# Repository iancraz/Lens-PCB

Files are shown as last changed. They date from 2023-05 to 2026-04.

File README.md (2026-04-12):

# Lens-Maker PCB
<a rel="license" href="http://creativecommons.org/licenses/by-nc-sa/4.0/">Creative Commons License</a><br />

This repository contains the design files for a printed circuit board (PCB) that enables the control of three stepper motors using an A4988 driver and an ESP32-WROOM32E microcontroller module. The PCB provides a compact and convenient solution for incorporating stepper motor control into your projects.

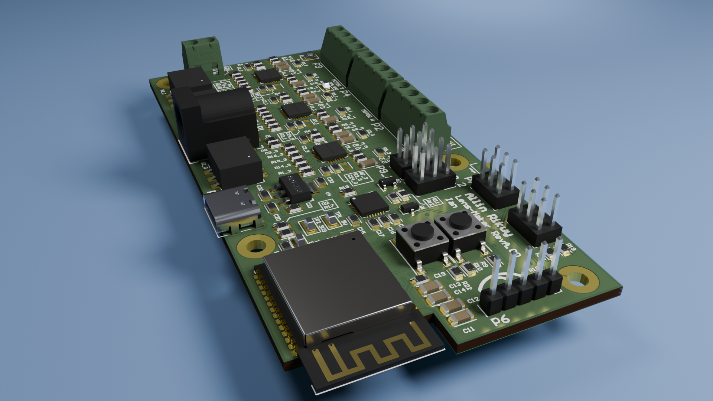
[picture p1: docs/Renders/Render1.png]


# Table of contents

* [Overview](#overview)
* [Features](#features)
* [Repository Structure](#repository-structure)
* [PCB Design](#pcb-design)
* [Bill of Materials (BOM)](#bill-of-materials)
* [Fabrication Instructions](#fabrication-instructions)
* [Contributing](#contributing)
* [License](#license)

## Overview
>[Table of contents](#table-of-contents)

The purpose of this PCB design is to simplify the process of controlling three stepper motors in your projects. By integrating an A4988 driver and an ESP32-WROOM32E module on a single board, you can easily interface with the motors and leverage the features of the ESP32 for advanced control and communication capabilities. In this design in particular three 2(A) stepper motors where needed to be controlled for a lens maker lathe, and the PCB was designed to fit the casing of the lathe.

# Features
>[Table of contents](#table-of-contents)

* **Compact**: The PCB is designed to be as small as possible while still providing the necessary features for stepper motor control.
* **Integrated A4988 Driver**: The A4988 driver is integrated into the PCB, eliminating the need for a separate driver module.
* **Integrated ESP32-WROOM32E Module**: The ESP32-WROOM32E module is integrated into the PCB, eliminating the need for a separate microcontroller module.
* **Integrated WiFi and Bluetooth Antennas**: The ESP32-WROOM32E module includes integrated WiFi and Bluetooth antennas, eliminating the need for external antennas.
* **Integrated Power Supply**: The PCB includes a 5V power supply that can be used to power the ESP32-WROOM32E module and the A4988 driver.
* **Integrated USB to UART Converter**: The PCB includes a USB to UART converter that can be used to program the ESP32-WROOM32E module and communicate with it via serial.
* **Integrated Reset Button**: The PCB includes a reset button that can be used to reset the ESP32-WROOM32E module.
* **I2C, SPI and GPIO Headers**: The PCB includes headers that can be used to connect I2C, SPI and GPIO devices to the ESP32-WROOM32E module.
* **JTAG Header**: The PCB includes a header that can be used to connect a JTAG debugger to the ESP32-WROOM32E module.
* **USB-C Connector**: The PCB includes a USB-C connector that can be used to power the PCB and communicate with the ESP32-WROOM32E module via USB.

# Repository Structure
>[Table of contents](#table-of-contents)

The repository is organized as follows:

* **`Lens-Maker`**: This directory contains the Altium design files for the PCB.
    * **`Project Outputs for Lens-Maker`**: This directory contains the Output files of the project.
        * **`GerberX2`**: This directory contains the Gerber files of the PCB.
        * **`Lens-Maker_Schematic.PDF`**: This file contains the PDF of the PCB.
        * **`ExportSTEP`**: This directory contains the 3D model of the PCB.
        * **`BOM`**: This directory contains the Bill of Materials of the PCB. 
* **`docs`**: This directory contains the documentation images for the PCB.
* **`LICENSE`**: This file contains the license for the PCB design.
* **`README.md`**: This file contains the documentation for the PCB design.

# PCB Design
>[Table of contents](#table-of-contents)

This PCB was design using Altium Designer 23.4.1. The PCB design files can be found in [here](./Lens-Maker). The PCB was designed to be as small as possible while still providing the necessary features for stepper motor control. The PCB is a 6-layer board with the following stackup:

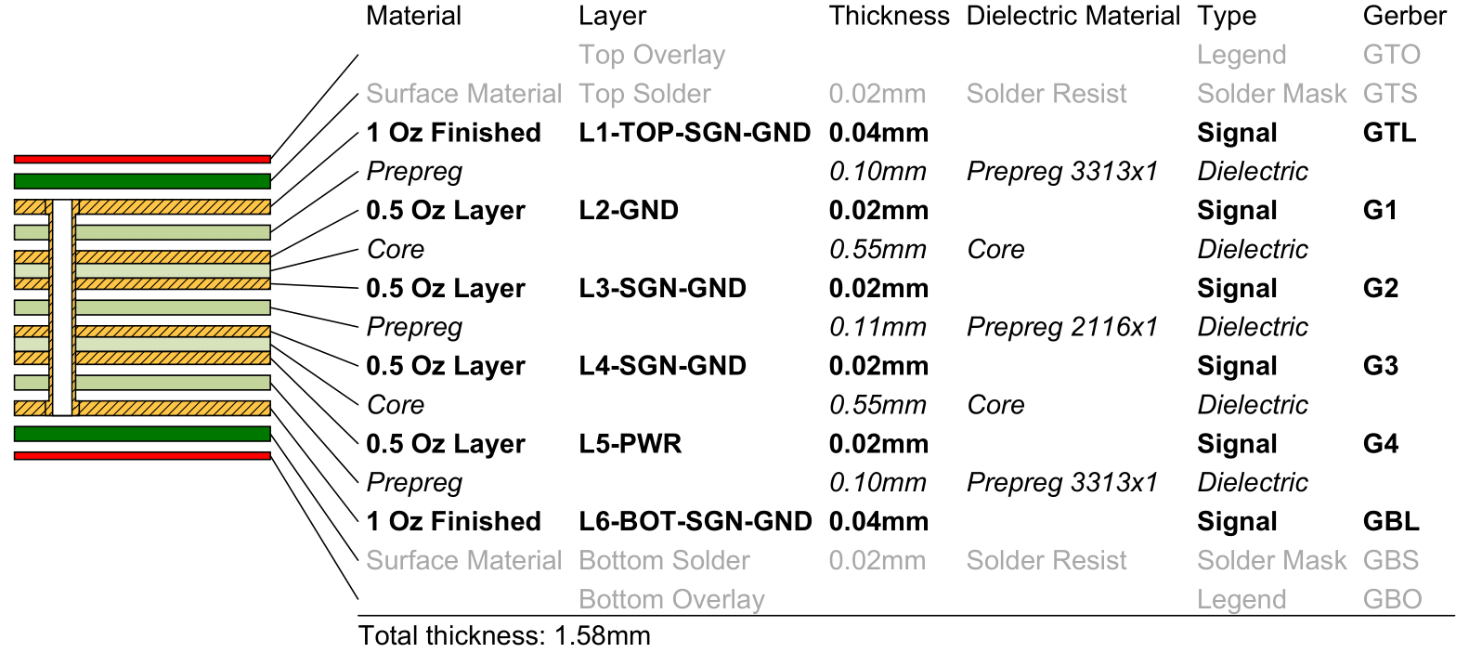
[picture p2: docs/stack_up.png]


The PCB was designed to fit the casing of the lens maker lathe, and the dimensions of the PCB are as follows:

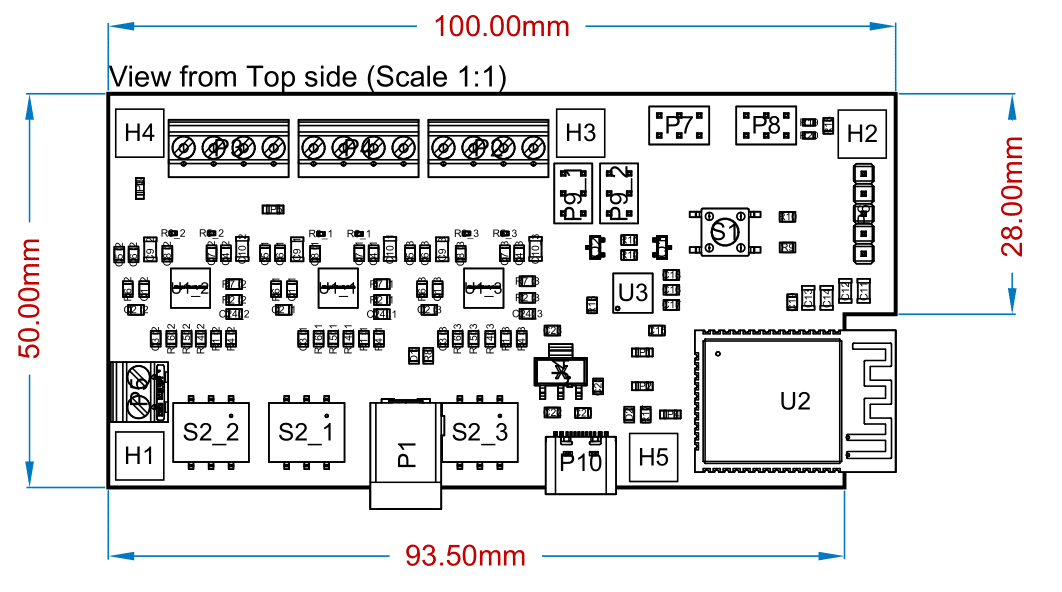
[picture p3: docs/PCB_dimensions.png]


## Microcontroller
>[Design](#design)

The design of this PCB starts at the desition of the MCU chosen for this purpose. Because of its simplicity and WiFi and Bluetooth antennas already integrated, an ESP32-WROOM-32E is chosen for this design. The main advantages of choosing this microcontroller are:

* **The form factor**: Its a MCU with WLAN capabilities in a size of a regular MCU.
* **Antennas integrated**: The benefits of using an ESP32 module and not an ESP32 MCU is to have the antennas already routed an integrated.
* **Easy to use**: Its many integration generated that ESP32 is a widely used MCU around the world, and this means there's a lot of information and resources to program this MCU.
* **Versatility**: If there is a future design, a new ESP32 module can be changed and the software will 'just work'.

## Stepper Driver
>[Design](#design)

For the Stepper driver, since this design is a prototype approach for the final goal, an A4988 driver was chosen, because of its previous use on a concept desing using the A4988 module from arduino. For future progress a driver change is needed to drive more heavy power Stepper motors. However this driver has a lot of advantages, its ease of use and simplicity makes it really easy tu use and code it, and its application in its own module has the heritage needed for the circuit to rely on.

## Schematic
>[Table of contents](#table-of-contents)

The Schematic of this PCB can be found in [here](./Lens-Maker/Project%20Outputs%20for%20Lens-Maker/Lens-Maker_Schematic.PDF). And below are some images sumarizing it. 

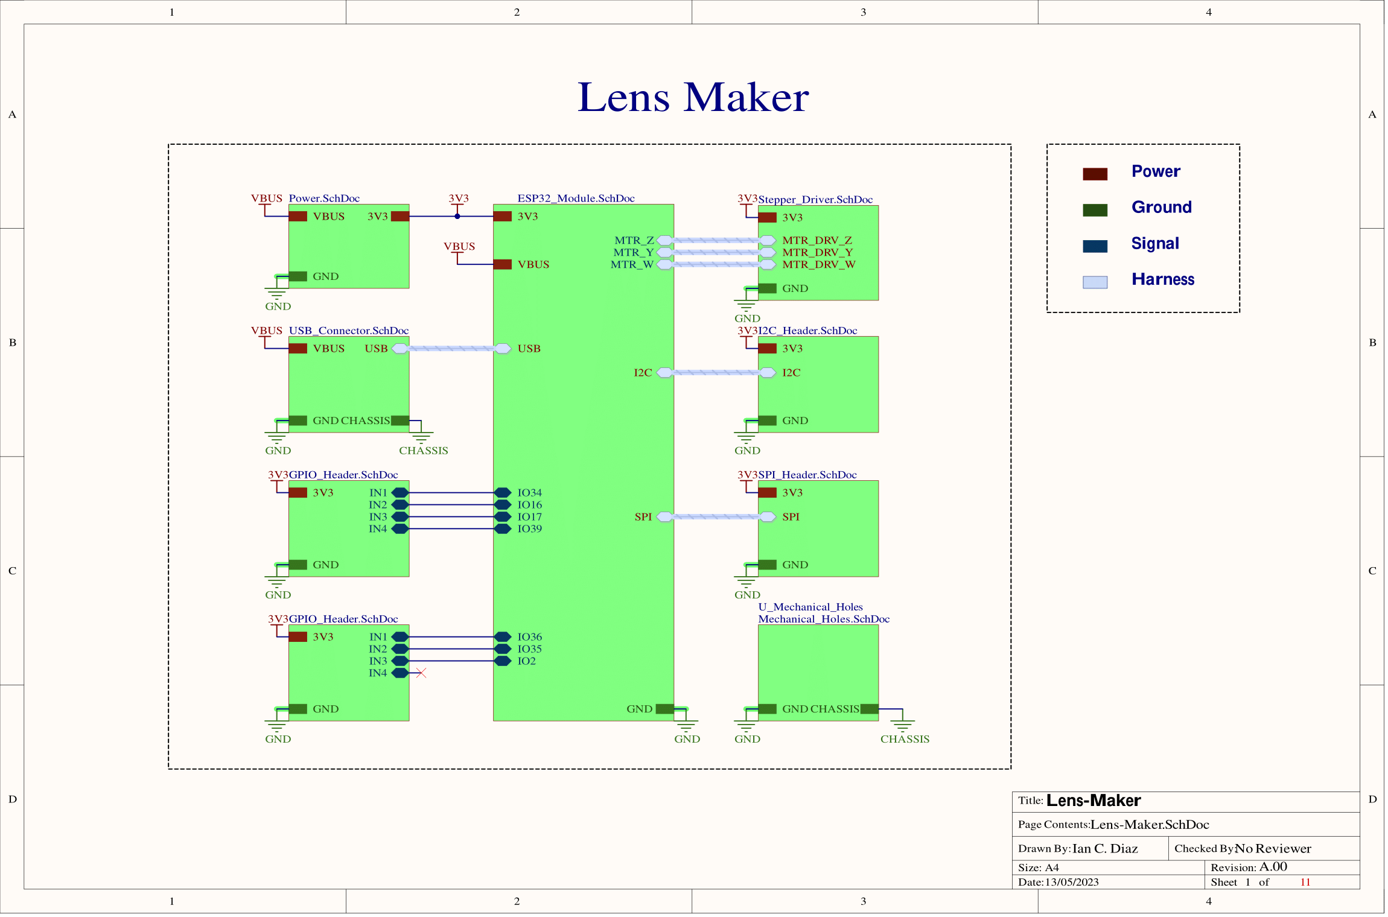
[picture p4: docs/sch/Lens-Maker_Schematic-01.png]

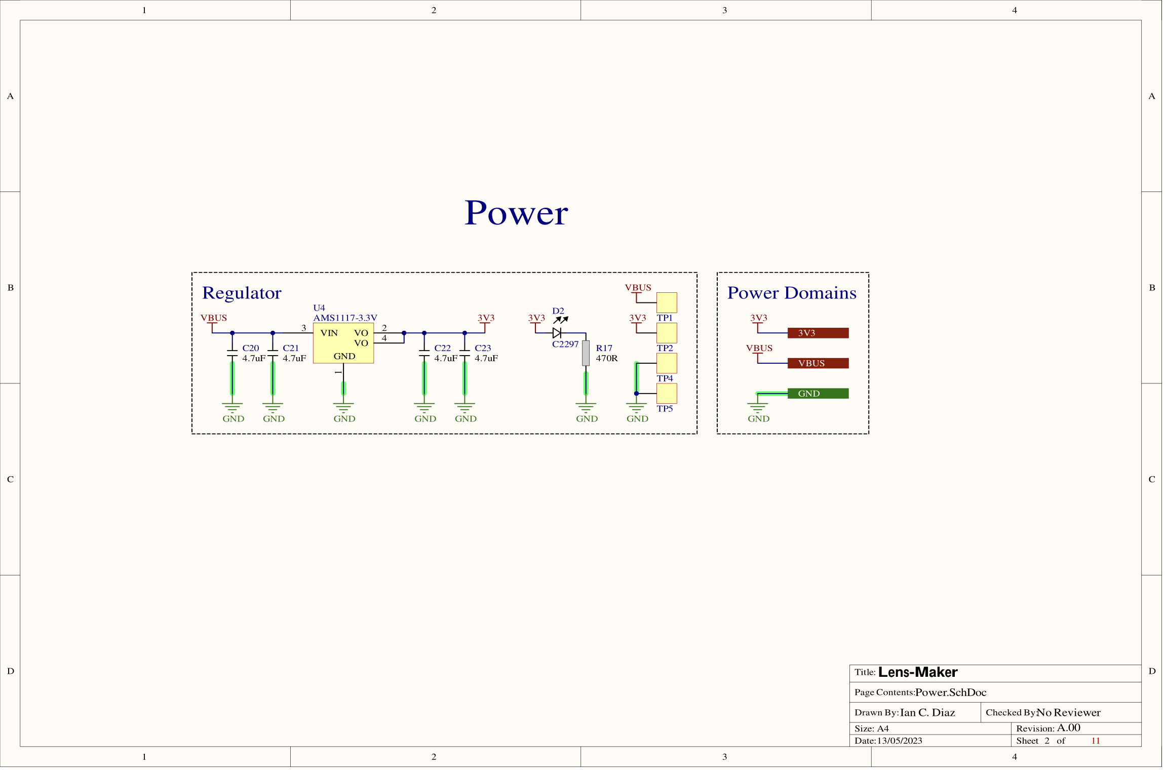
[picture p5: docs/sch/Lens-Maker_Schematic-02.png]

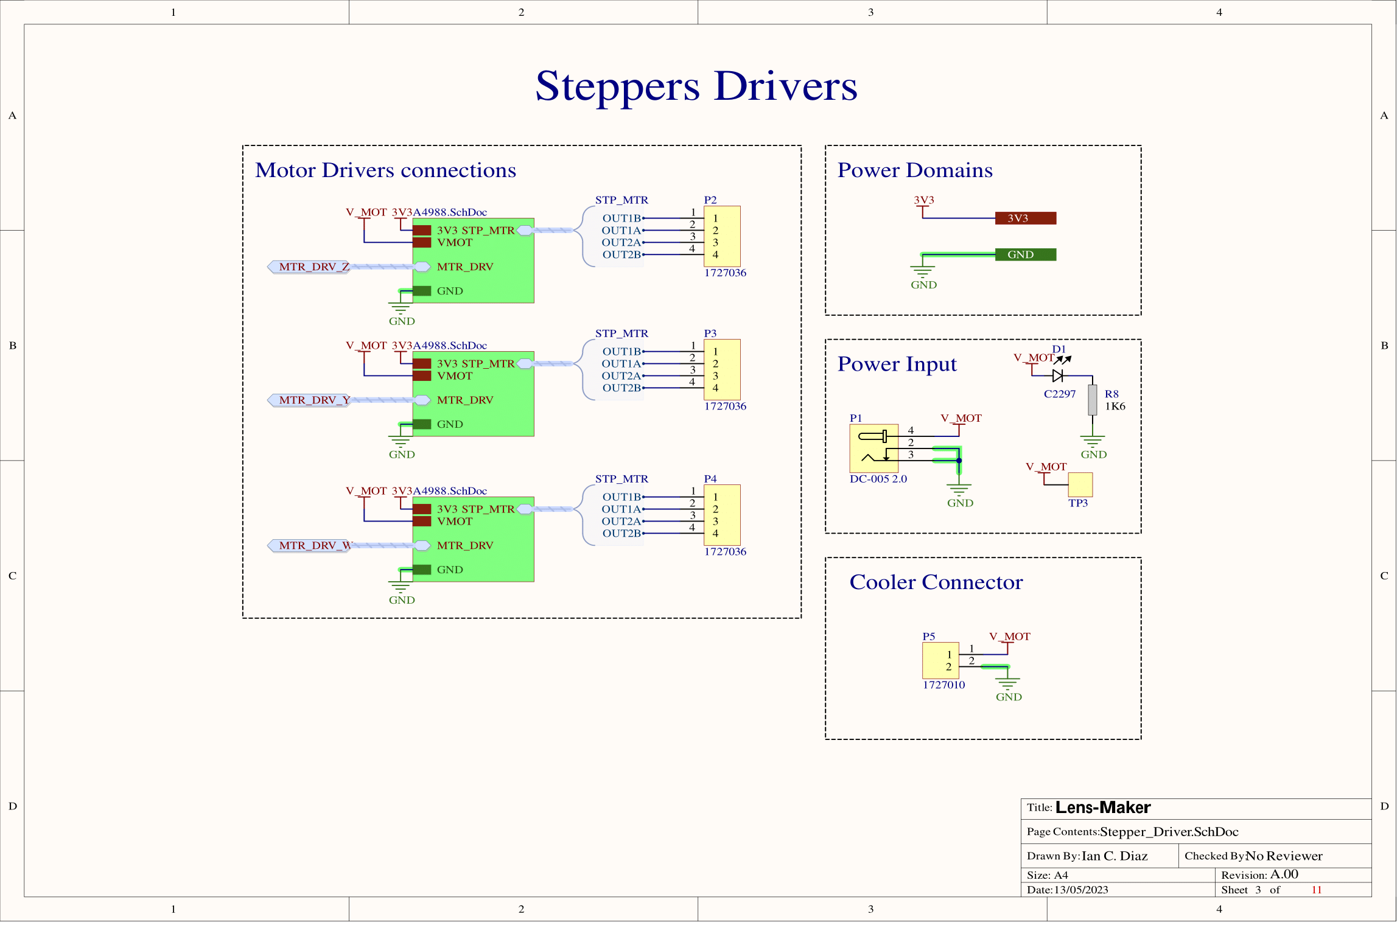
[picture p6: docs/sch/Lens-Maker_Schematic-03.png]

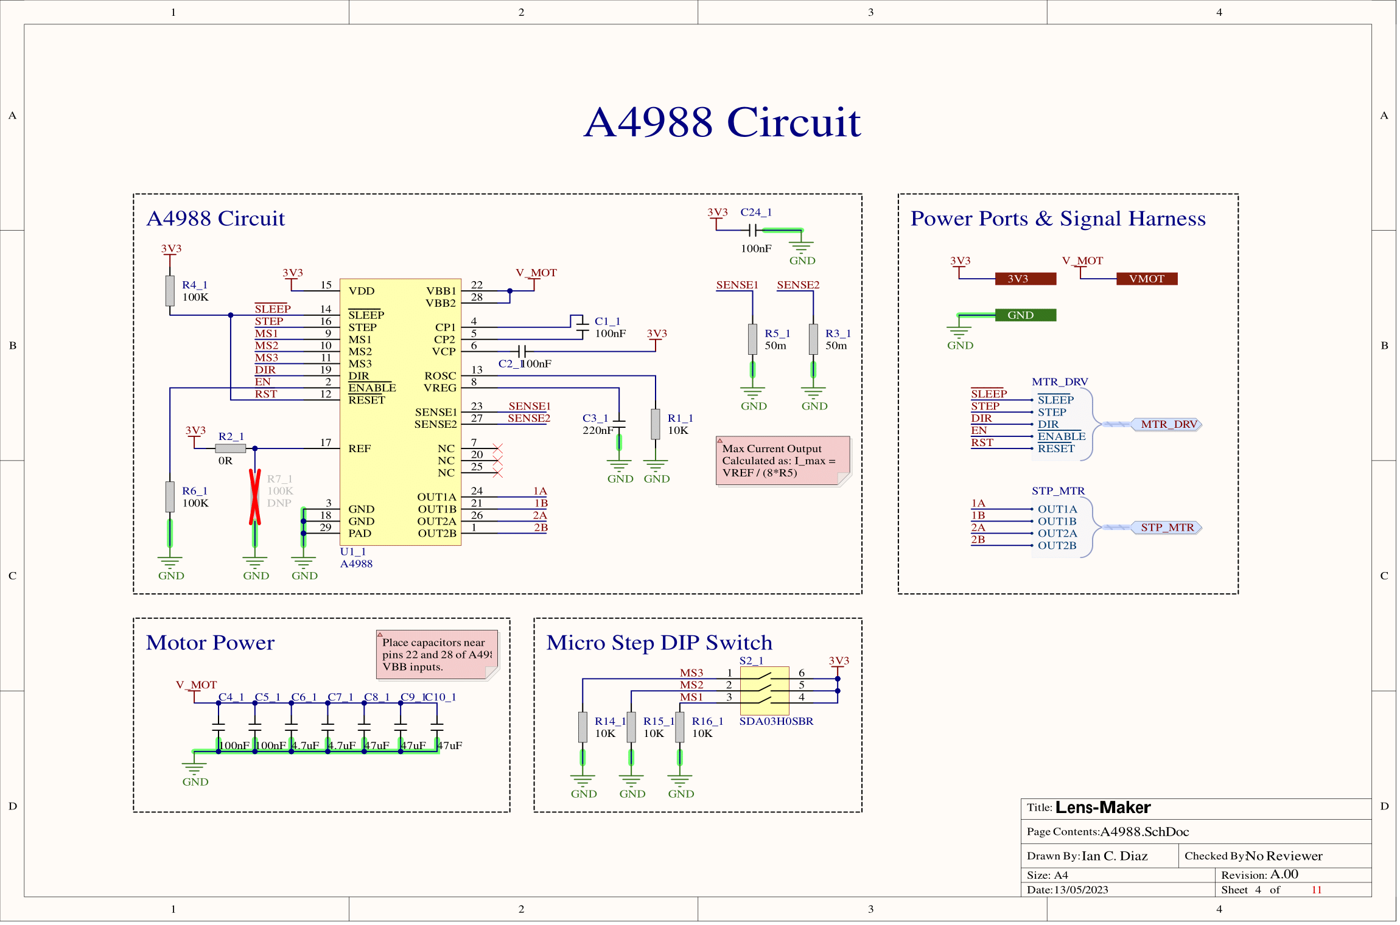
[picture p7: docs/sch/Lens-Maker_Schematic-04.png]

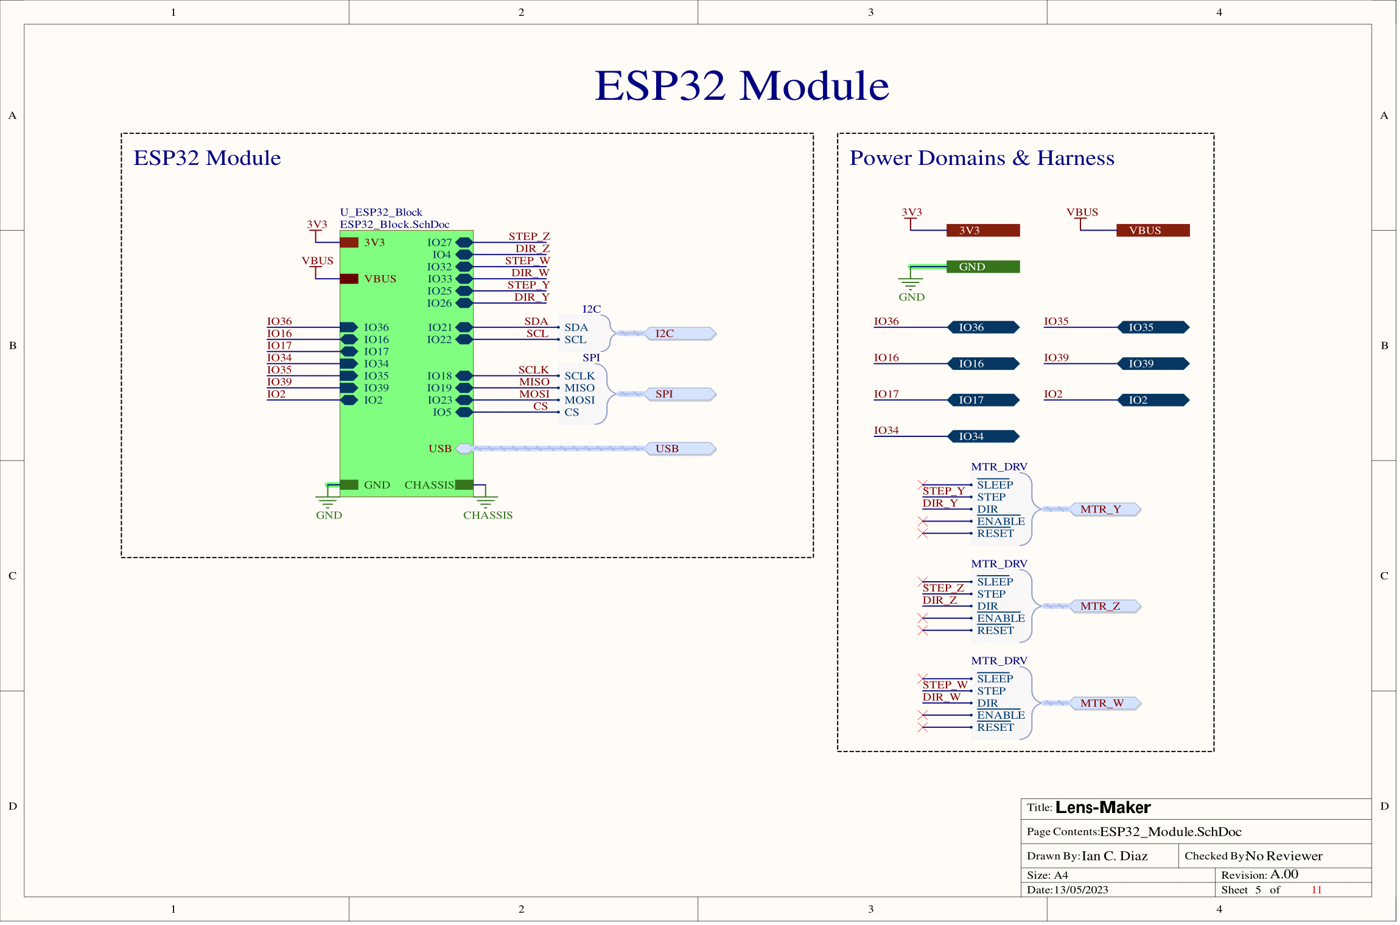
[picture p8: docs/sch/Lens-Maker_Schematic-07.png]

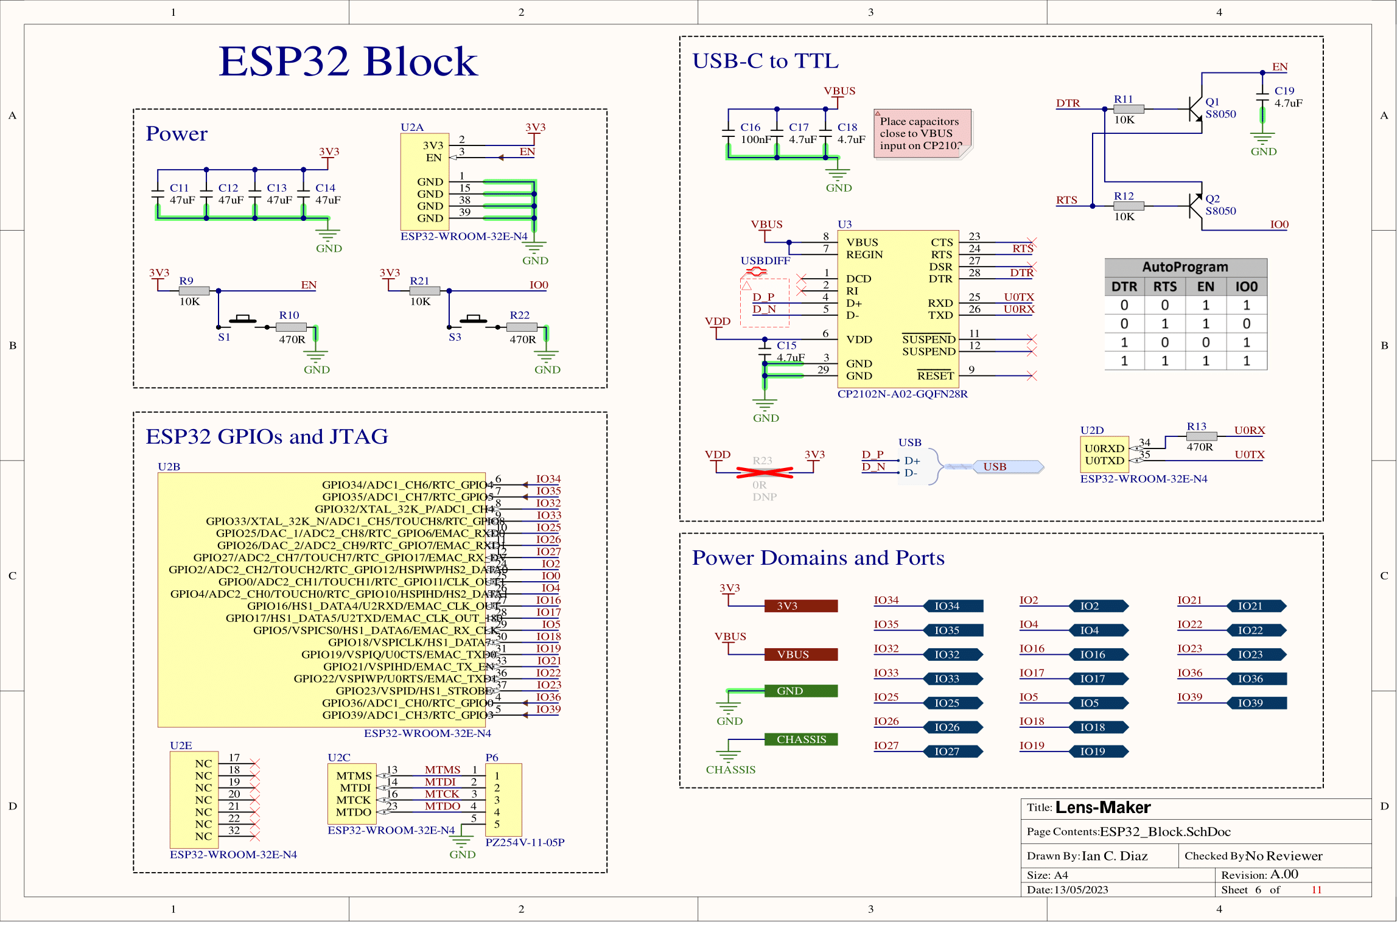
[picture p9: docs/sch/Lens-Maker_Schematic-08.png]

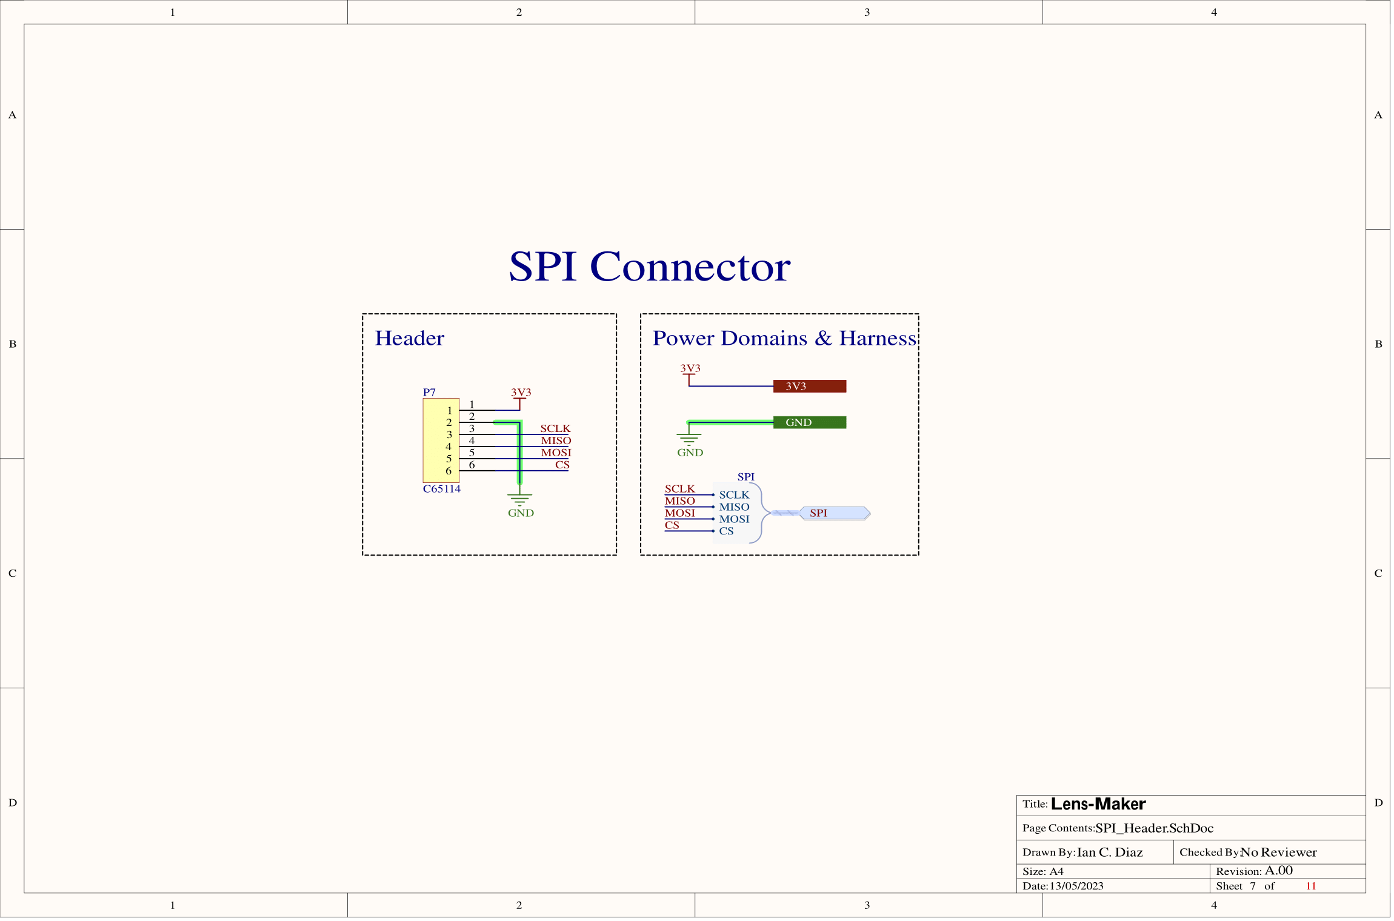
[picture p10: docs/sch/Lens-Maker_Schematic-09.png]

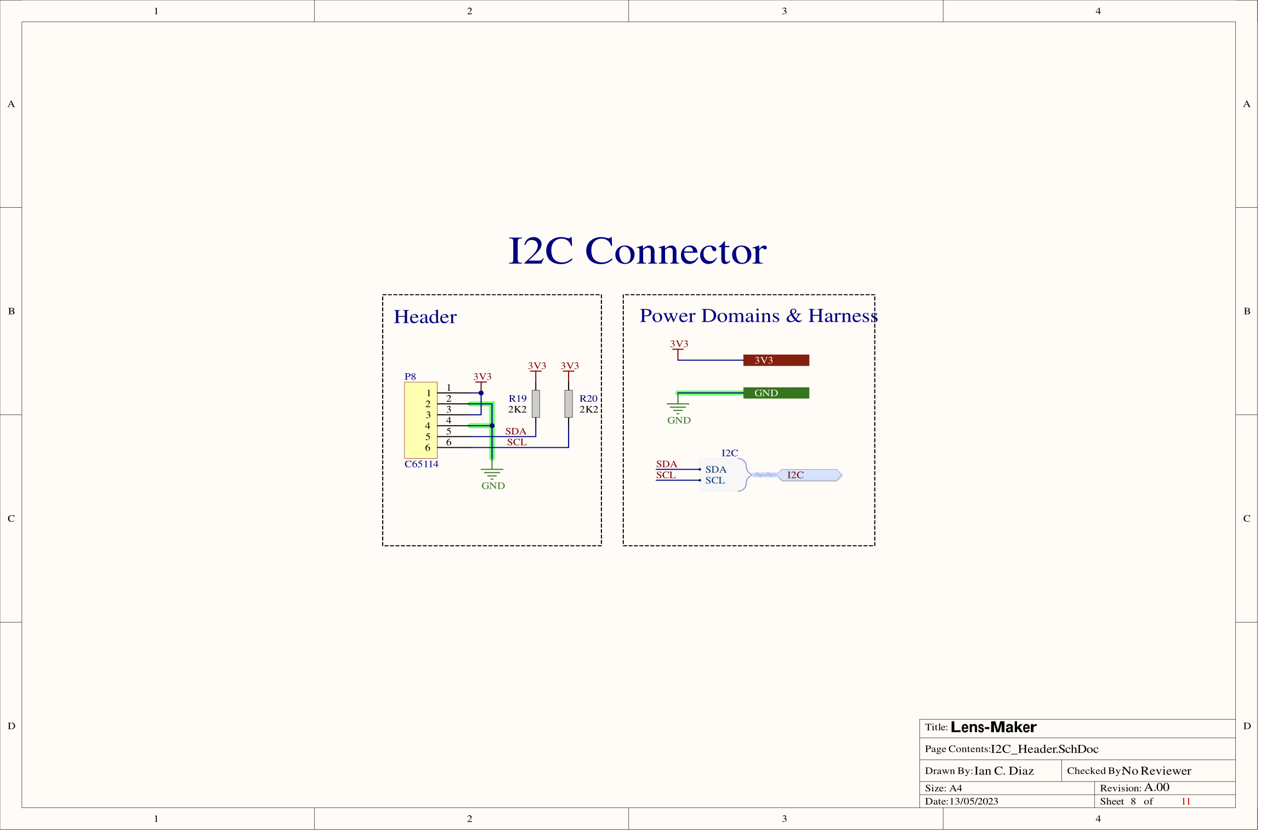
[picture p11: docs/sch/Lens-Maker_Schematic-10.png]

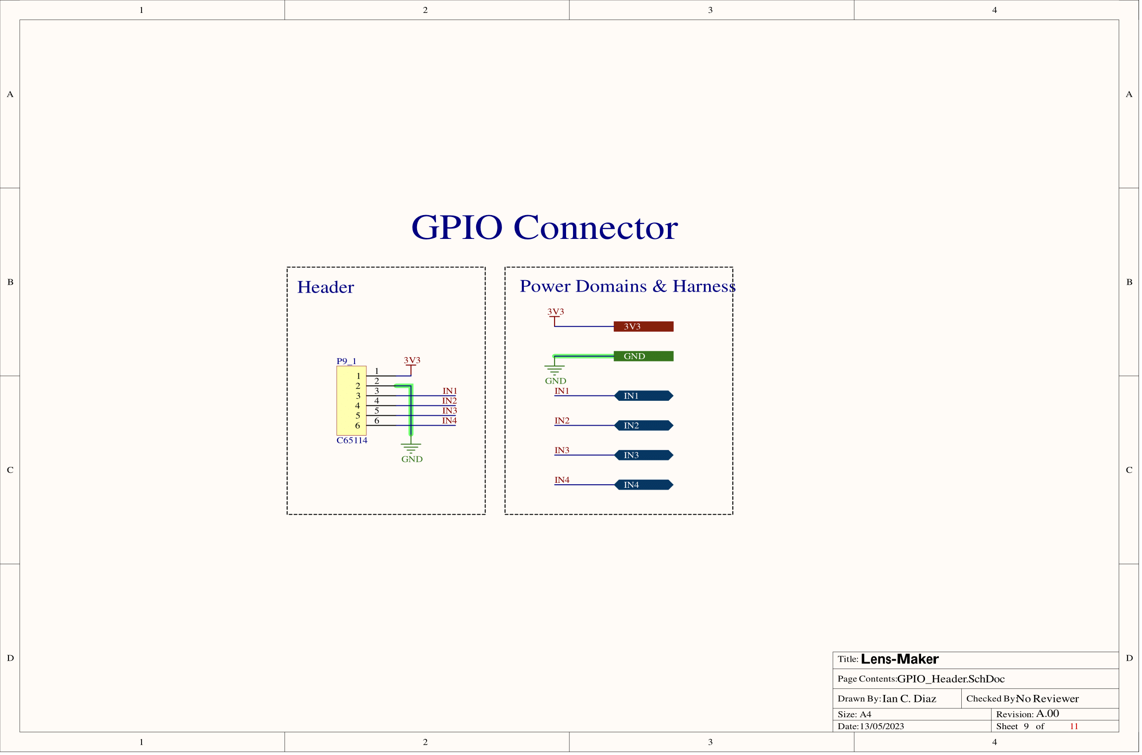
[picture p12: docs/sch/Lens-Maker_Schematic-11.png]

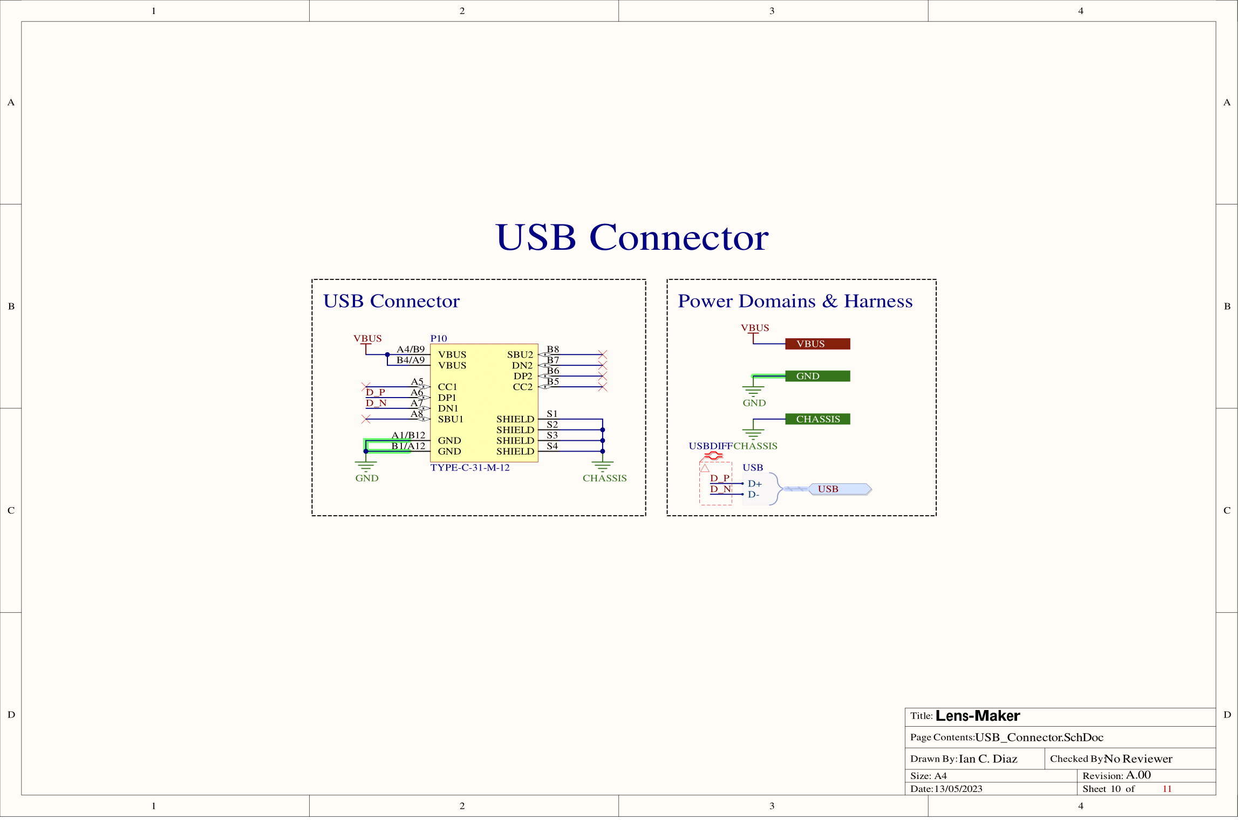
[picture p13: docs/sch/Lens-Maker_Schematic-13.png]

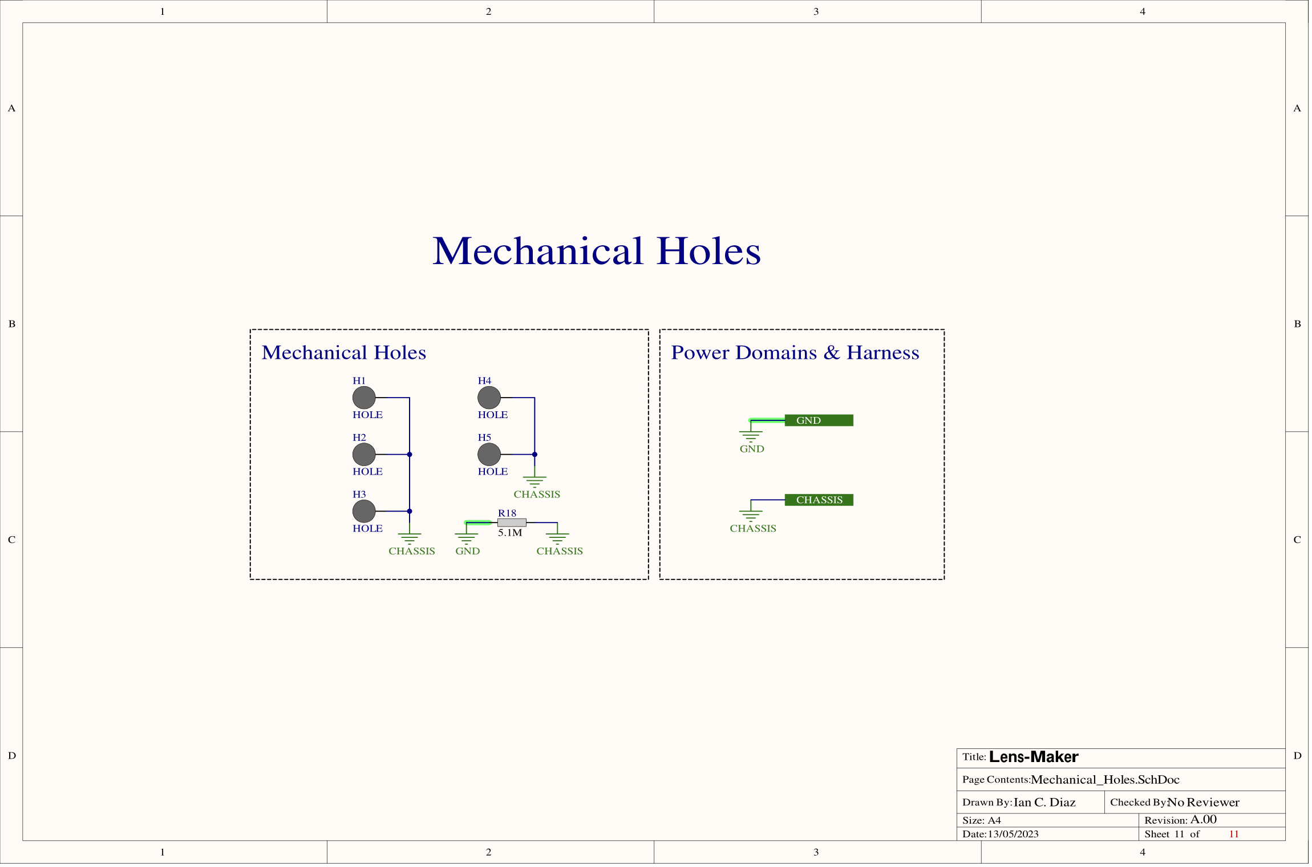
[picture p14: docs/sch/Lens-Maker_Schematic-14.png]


# Bill of Materials
>[Table of contents](#table-of-contents)

| Designator | Footprint | Value | Manufacturer | Manufacturer Part Number | Supplier | Supplier Part Number | Description | Quantity |
| --- | --- | ----- | --- | --- | --- | --- | --- | --- |
| C1_1, C1_2, C1_3, C2_1, C2_2, C2_3, C4_1, C4_2, C4_3, C5_1, C5_2, C5_3, C16, C24_1, C24_2, C24_3 | 0805 | 100nF | YAGEO | CC0805KRX7R9BB104 | JLCPCB | C49678 | 50V 100nF X7R ±10% 0805 Multilayer Ceramic Capacitors MLCC - SMD/SMT ROHS | 16 |
| C3_1, C3_2, C3_3 | 0805 | 220nF | Samsung Electro-Mechanics | CL21B224KBFNNNE | JLCPCB | C5378 | 50V 220nF X7R ±10% 0805 Multilayer Ceramic Capacitors MLCC - SMD/SMT ROHS | 3 |
| C6_1, C6_2, C6_3, C7_1, C7_2, C7_3, C15, C17, C18, C19, C20, C21, C22, C23 | 0805 | 4.7uF | Samwha Capacitor | CS2012X7R475K350NRE | JLCPCB | C560882 | 35V 4.7uF X7R ±10% 0805 Multilayer Ceramic Capacitors MLCC - SMD/SMT ROHS | 14 |
| C8_1, C8_2, C8_3, C9_1, C9_2, C9_3, C10_1, C10_2, C10_3, C11, C12, C13, C14 | 1206 | 47uF  | TDK | C3216X5R1E476MTJ00E | JLCPCB | C76659 | 25V 47uF X5R ±20% 1206 Multilayer Ceramic Capacitors MLCC - SMD/SMT ROHS | 13 |
| D1, D2 | 0805 | | Hubei KENTO Elec | C2297 | JLCPCB | C2297 | 0805 Light Emitting Diodes (LED) ROHS | 2 |
| H1, H2, H3, H4, H5 | HOLE_M3 | | | | | | Hole M3 | 5 |
| P1 | DC-005 2.0 | | BOOMELE(Boom Precision Elec) | DC-005 2.0 | JLCPCB | C16214 | Shrouded DC Power Receptacle 2mm 6.4mm Plugin AC/DC Power Connectors ROHS | 1 |
| P2, P3, P4 | 1727036 | | Phoenix Contact | 1727036 | JLCPCB | C457200 | TERM BLK 4P SIDE ENT 3.81MM PCB | 3 |
| P5 | 1727010 | | Phoenix Contact | 1727010 | JLCPCB | C89123 | TERM BLK 2P SIDE ENT 3.81MM PCB | 1 |
| P6 | PZ254V-11-05P | | XFCN | PZ254V-11-05P | JLCPCB | C492404 | Straight Square Pins 2.5mm 6mm -40℃~+105℃ 3mm 5 2.54mm Black Brass 1x5P Plugin,P=2.54mm Pin Headers ROHS | 1 |
| P7, P8, P9_1, P9_2 | HEADER 3X2 | | BOOMELE(Boom Precision Elec) | C65114 | JLCPCB | C65114 | Straight 2 6 2.54mm Black Straight,P=2.54mm Pin Headers ROHS | 4 |
| P10 | TYPE-C-31-M-12  | | Korean Hroparts Elec | TYPE-C-31-M-12 | JLCPCB | C165948 | USB C SMD Connector | 1 |
| Q1, Q2 | SOT-23-3 | | JSMSEMI | S8050 | JLCPCB | C916390 | 25V 300mW 500mA SOT-23 Bipolar Transistors - BJT ROHS | 2 |
| R1_1, R1_2, R1_3, R9, R11, R12, R14_1, R14_2, R14_3, R15_1, R15_2, R15_3, R16_1, R16_2, R16_3, R21 | 0805 | 10K | UNI-ROYAL(Uniroyal Elec) | 0805W8F1002T5E | JLCPCB | C17414 | 125mW Thick Film Resistors ±1% 10kΩ 0805 Chip Resistor - Surface Mount ROHS | 16 |
| R2_1, R2_2, R2_3 | 0805 | 0R | PANASONIC | ERJ6GEY0R00V | JLCPCB | C169855 | 125mW 0Ω 0805 Chip Resistor - Surface Mount ROHS | 3 |
| R3_1, R3_2, R3_3, R5_1, R5_2, R5_3 | 0805 | 50m | YAGEO | PE0805FRF7W0R05L | JLCPCB | C858613 | 250mW ±1% 50mΩ 0805 Chip Resistor - Surface Mount ROHS | 6 |
| R4_1, R4_2, R4_3, R6_1, R6_2, R6_3 | 0805 | 100K  | FH (Guangdong Fenghua Advanced Tech) | RS-05K104JT | JLCPCB | C118844 | 125mW ±5% 100kΩ 0805 Chip Resistor - Surface Mount ROHS | 6 |
| R8 | 0805 | 1K6 | Resistor.Today | AECR0805F1K60K9 | JLCPCB | C352253 | 125mW Thick Film Resistors ±1% 1.6kΩ 0805 Chip Resistor - Surface Mount ROHS | 1 |
| R10, R13, R17, R22 | 0805 | 470R  | UNI-ROYAL(Uniroyal Elec) | 0805W8F4700T5E | JLCPCB | C17710 | 125mW Thick Film Resistors ±1% 470Ω 0805 Chip Resistor - Surface Mount ROHS | 4 |
| R18 | 0805 | 5.1M  | TA-I Tech | RM10FTN5104 | JLCPCB | C156163 | 125mW Thick Film Resistors ±1% 5.1MΩ 0805 Chip Resistor - Surface Mount ROHS | 1 |
| R19, R20 | 0805 | 2K2 | LIZ Elec | CR0805J80222G | JLCPCB | C101970 | 125mW Thick Film Resistors ±5% 2.2kΩ 0805 Chip Resistor - Surface Mount ROHS | 2 |
| S1, S3 | PUSHBUTTON_2 | | C&K | PTS645SM43SMTR92LFS | JLCPCB | C221880 | SWITCH TACTILE SPST-NO 0.05A 12V | 2 |
| S2_1, S2_2, S2_3 | SDA03H0SBR | | C&K | SDA03H0SBR | JLCPCB | C221950 | SWITCH SLIDE DIP SPST 25MA 24V | 3 |
| TP1, TP2, TP3, TP4, TP5 | 5015 | | Ronghe | RH-5015 | JLCPCB | C5199798 | Thimble/Copper Rod/Test Ring ROHS | 5 |
| U1_1, U1_2, U1_3 | 28-QFN | | Allegro MicroSystems, LLC | A4988SETTR-T | JLCPCB | C38437 | IC MTR DRVR BIPOLAR 3-5.5V 28QFN | 3 |
| U2 | ESP32-WROOM-32E | | Espressif Systems | ESP32-WROOM-32E-N4 | JLCPCB | C701341 | RX TXRX MOD WIFI TRACE ANT SMD | 1 |
| U3 | CP2102N | | SILICON LABS | CP2102N-A02-GQFN28R | JLCPCB | C964632 | QFN-28 USB ICs ROHS | 1 |
| U4 | SOT-223 | | Shenzhen Fuman Elec | AMS1117-3.3V | JLCPCB | C173386 | IC-1117 V.reg. 1A 3V3 SOT223 SMD Ams | 1 |

# Fabrication Instructions
>[Table of contents](#table-of-contents)

The fabrication instructions can be found in [here](./Lens-Maker/Project%20Outputs%20for%20Lens-Maker/Lens-Maker_Fabrication_Instructions.PDF) and the Gerber files are located in [this directory](./Lens-Maker/Project%20Outputs%20for%20Lens-Maker/GerberX2/). For the PCBA the assembly drawing can be found [here](./Lens-Maker/Project%20Outputs%20for%20Lens-Maker/Lens-Maker_Assembly_Drawings.PDF).

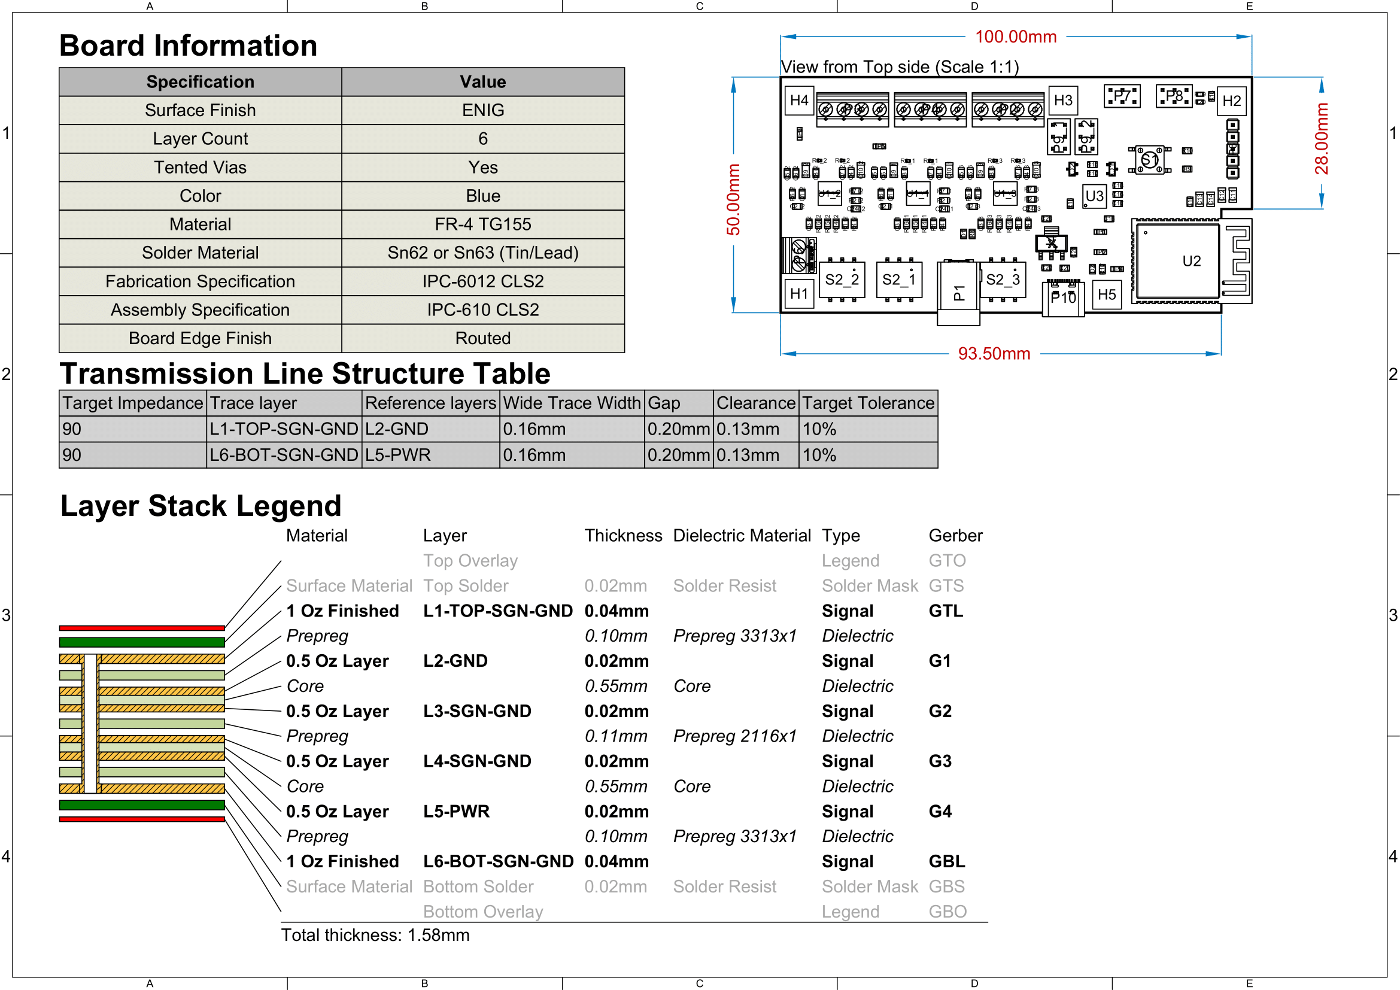
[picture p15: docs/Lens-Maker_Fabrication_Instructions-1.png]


## 3D Model
>[Table of contents](#table-of-contents)

A 3D model of the PCB is available for the design and manufacture of the lathe casing located in [here](./Lens-Maker/Project%20Outputs%20for%20Lens-Maker/ExportSTEP/Lens-Maker_3D_STEP.step).

## Some pictures
>[Table of contents](#table-of-contents)

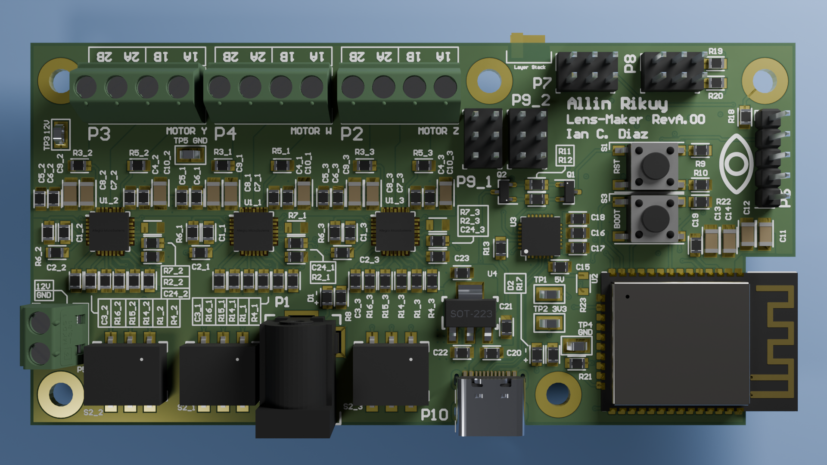
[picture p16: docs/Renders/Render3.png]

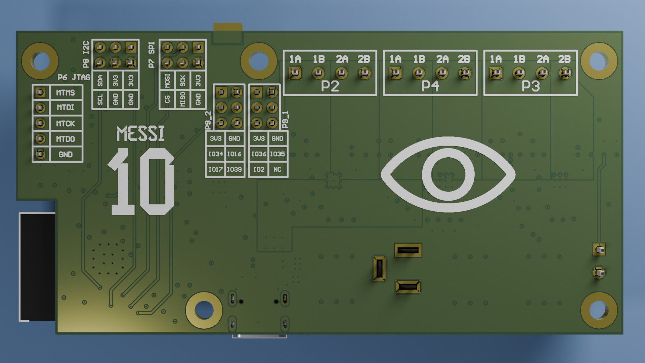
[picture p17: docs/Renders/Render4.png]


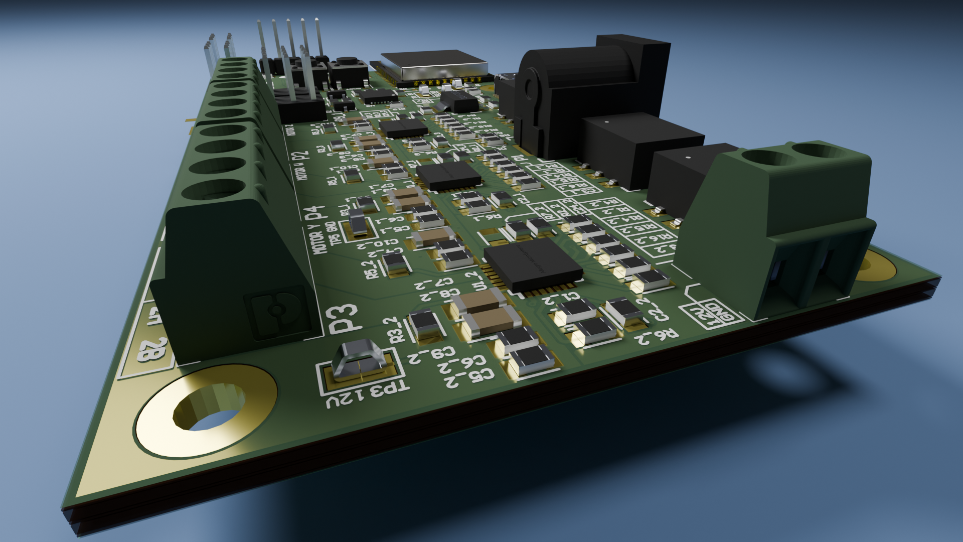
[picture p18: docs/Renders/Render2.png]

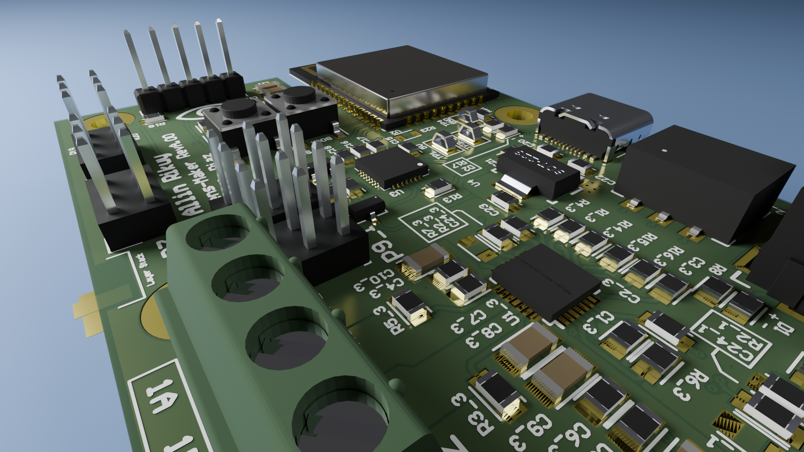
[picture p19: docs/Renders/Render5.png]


# Contributing
>[Table of contents](#table-of-contents)

Please do not hesitate to reach out to me if you find any issue with the code or if you have any questions.

* Personal email: [ianczdiaz@gmail.com](mailto:ianczdiaz@gmail.com)

* LinkedIn Profile: [https://www.linkedin.com/in/iancraz/](https://www.linkedin.com/in/iancraz/)

# License
>[Table of contents](#table-of-contents)

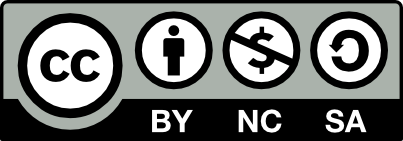
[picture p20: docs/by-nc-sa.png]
<br />

```
Copyright 2023 Ian Cruz Diaz. 

This project and all its components, including the PCB design files, Schematics and Output Files are 
licensed under a Creative Commons Attribution-NonCommercial-ShareAlike 4.0 International License. You 
can find a copy of the License at ./LICENSE.md or at https://creativecommons.org/licenses/by-nc-sa/4.0/legalcode.
```

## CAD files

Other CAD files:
docs/Renders/Project/Render.blend

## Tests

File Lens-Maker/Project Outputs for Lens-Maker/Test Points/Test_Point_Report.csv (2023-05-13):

Net | Name | X Coord | Y Coord | Side | Hole Size | Type
GND | TP5-1 | 823.969mil | 1390mil | Top | 0mil | Surface mount
VBUS | TP1-1 | 2670mil | 675mil | Top | 0mil | Surface mount
3V3 | TP2-1 | 2670mil | 526.52mil | Top | 0mil | Surface mount
V_MOT | TP3-1 | 157.481mil | 1495mil | Top | 0mil | Surface mount
GND | TP4-1 | 2810mil | 410.03mil | Top | 0mil | Surface mount

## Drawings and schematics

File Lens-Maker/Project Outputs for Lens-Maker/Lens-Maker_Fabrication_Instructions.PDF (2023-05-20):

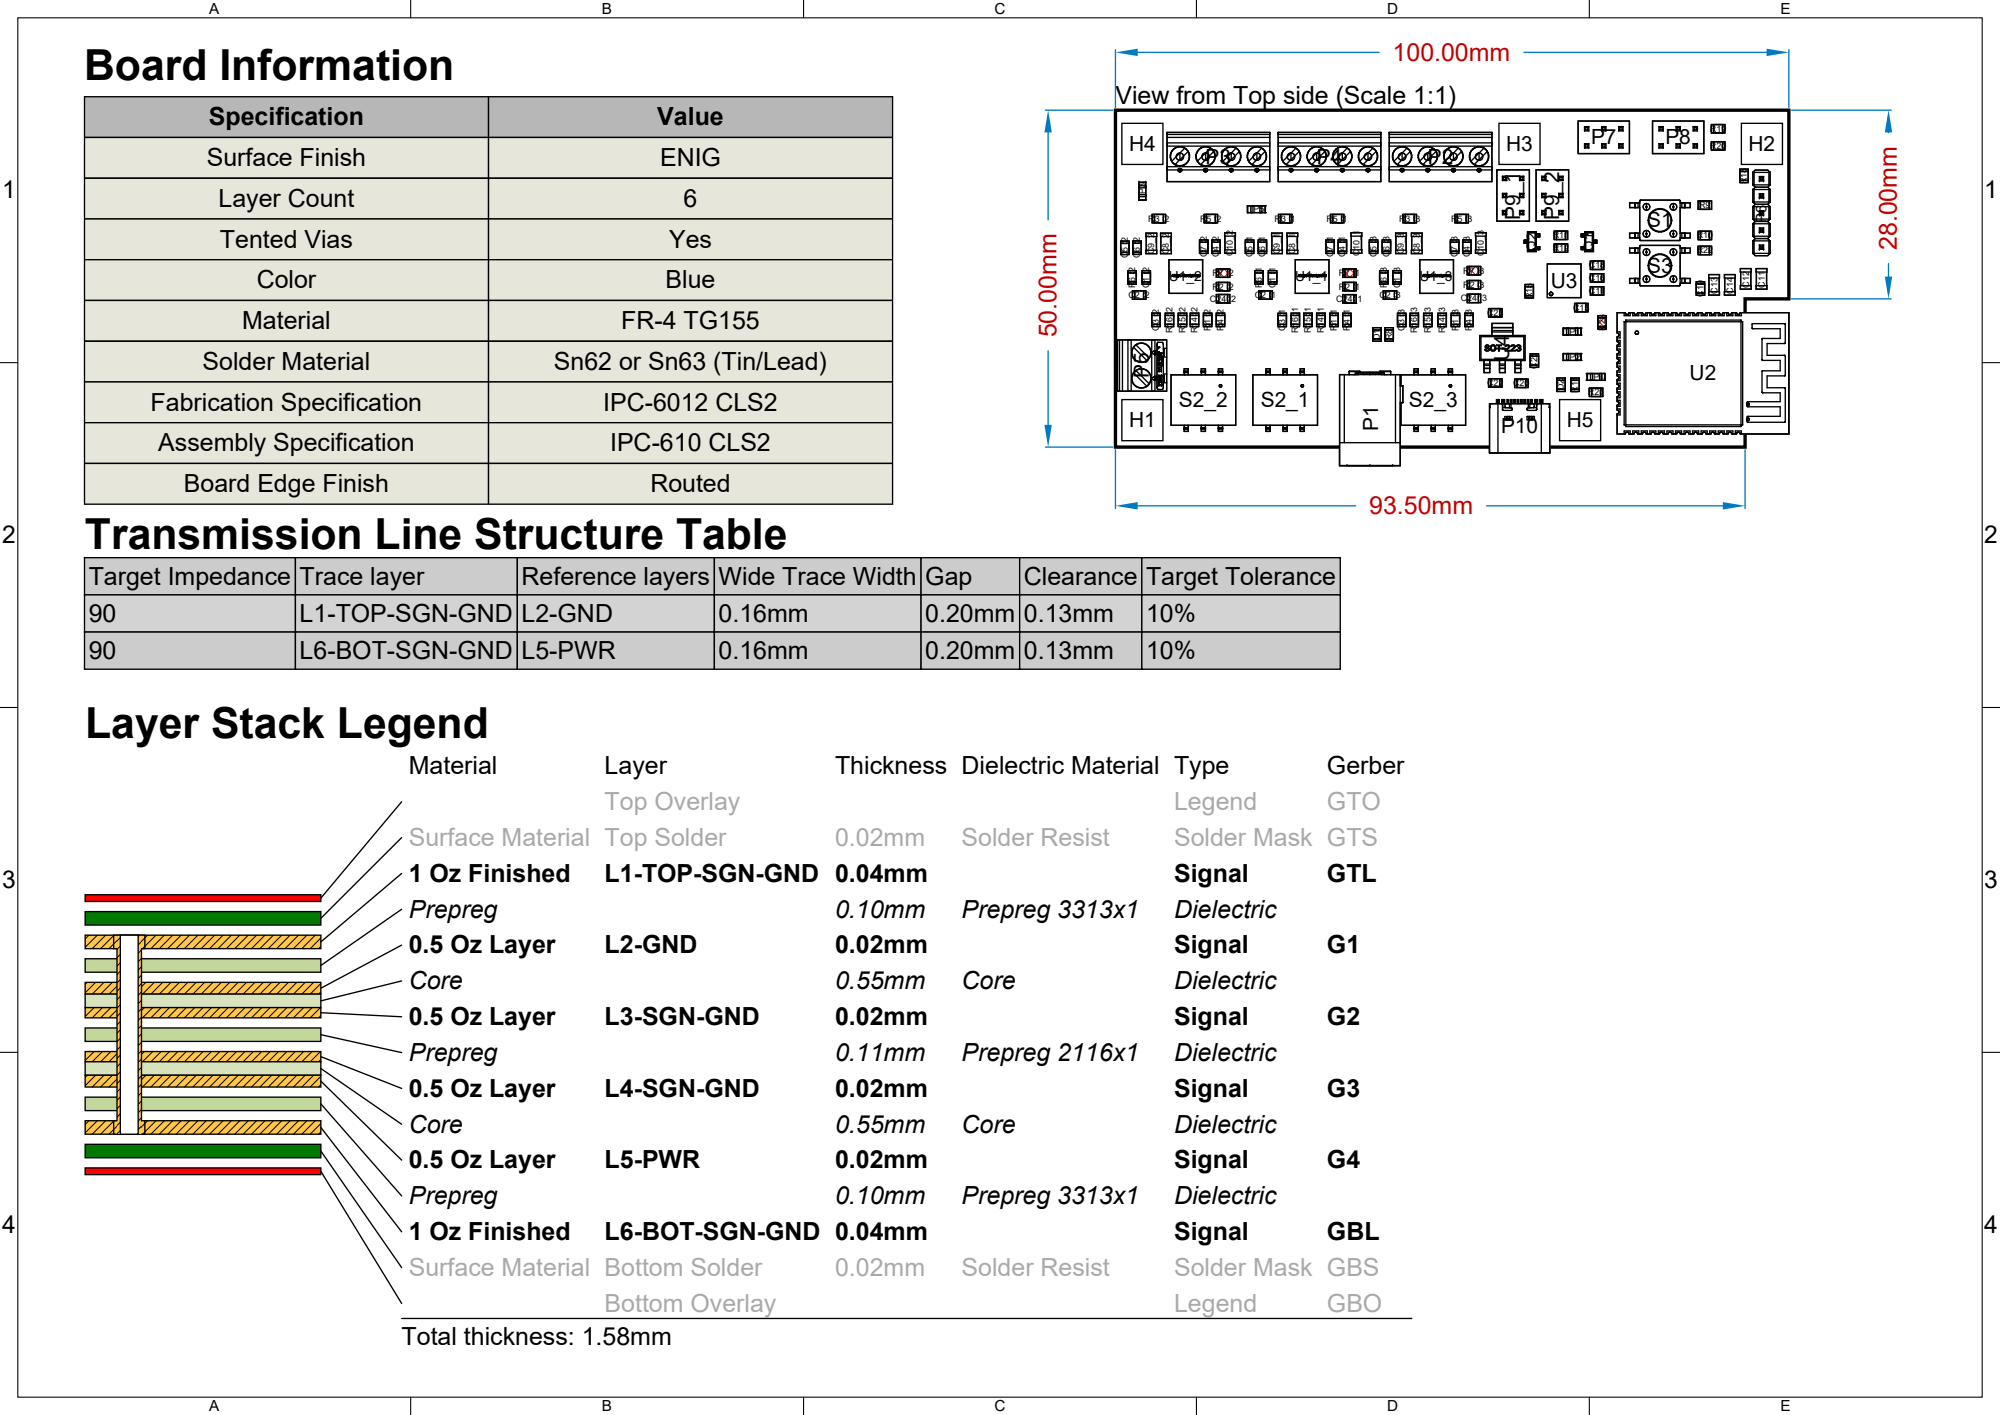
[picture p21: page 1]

View from Top side (Scale 1:1)

Solder Material
Fabrication Specification
Assembly Specification
Board Edge Finish
Transmission Line Structure Table
Target Impedance
Layer Stack Legend

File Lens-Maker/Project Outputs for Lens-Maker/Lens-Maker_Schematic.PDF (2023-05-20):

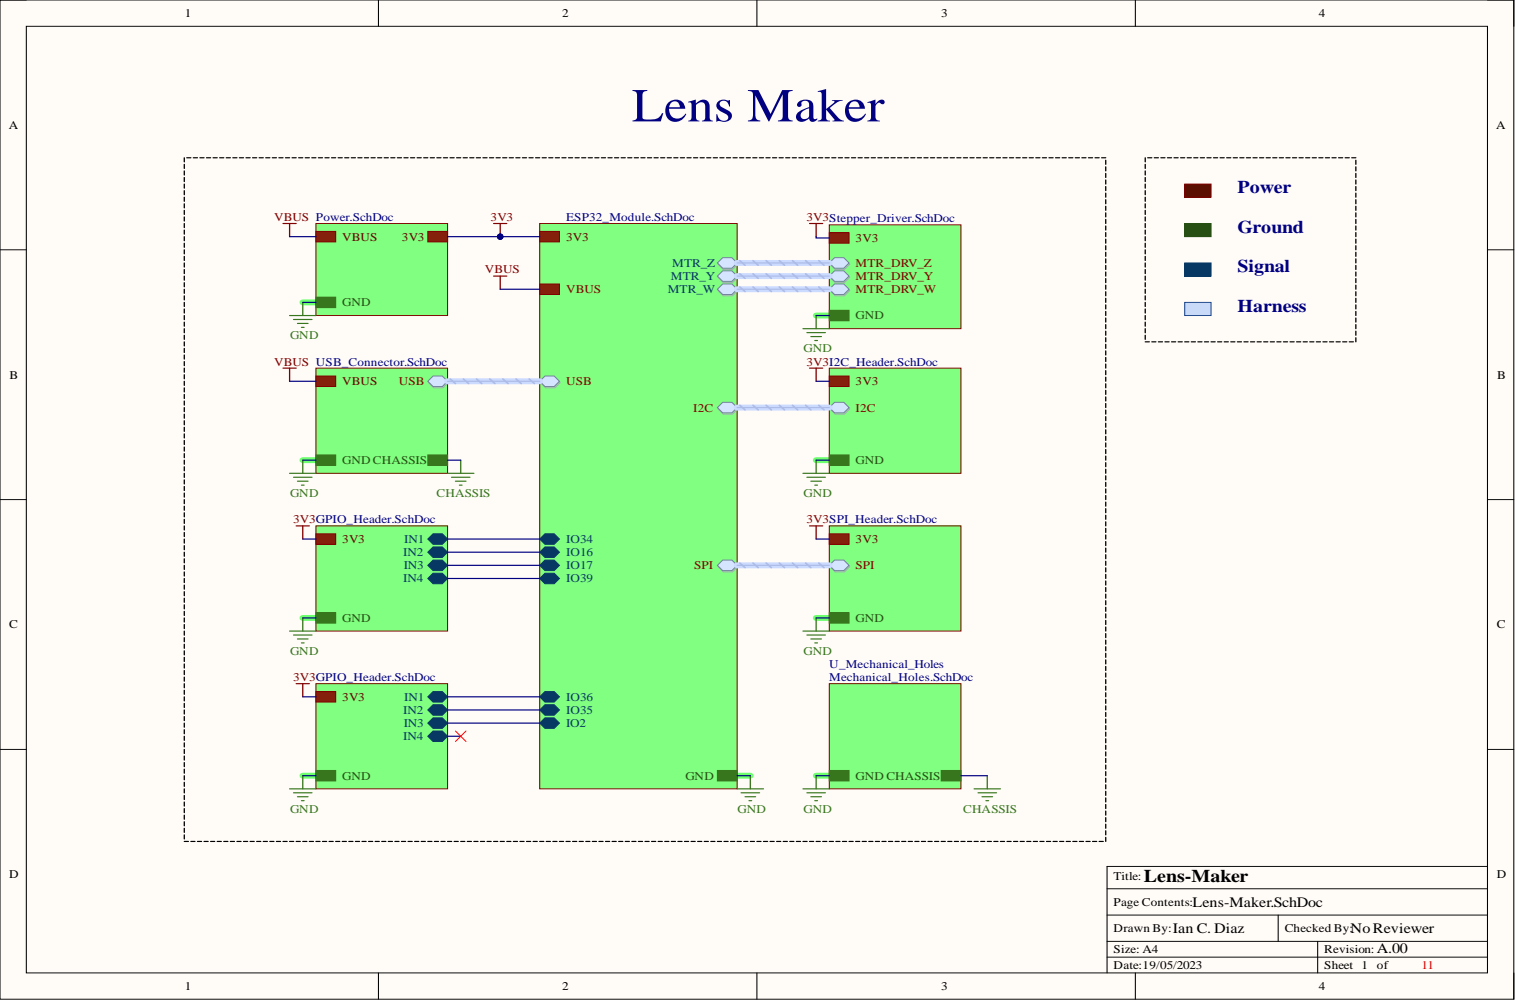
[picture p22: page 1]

Page Contents:Lens-Maker.SchDoc

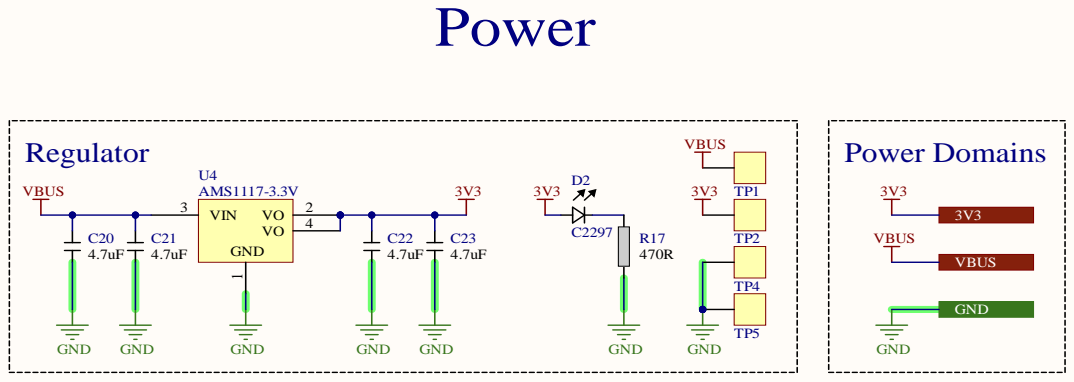
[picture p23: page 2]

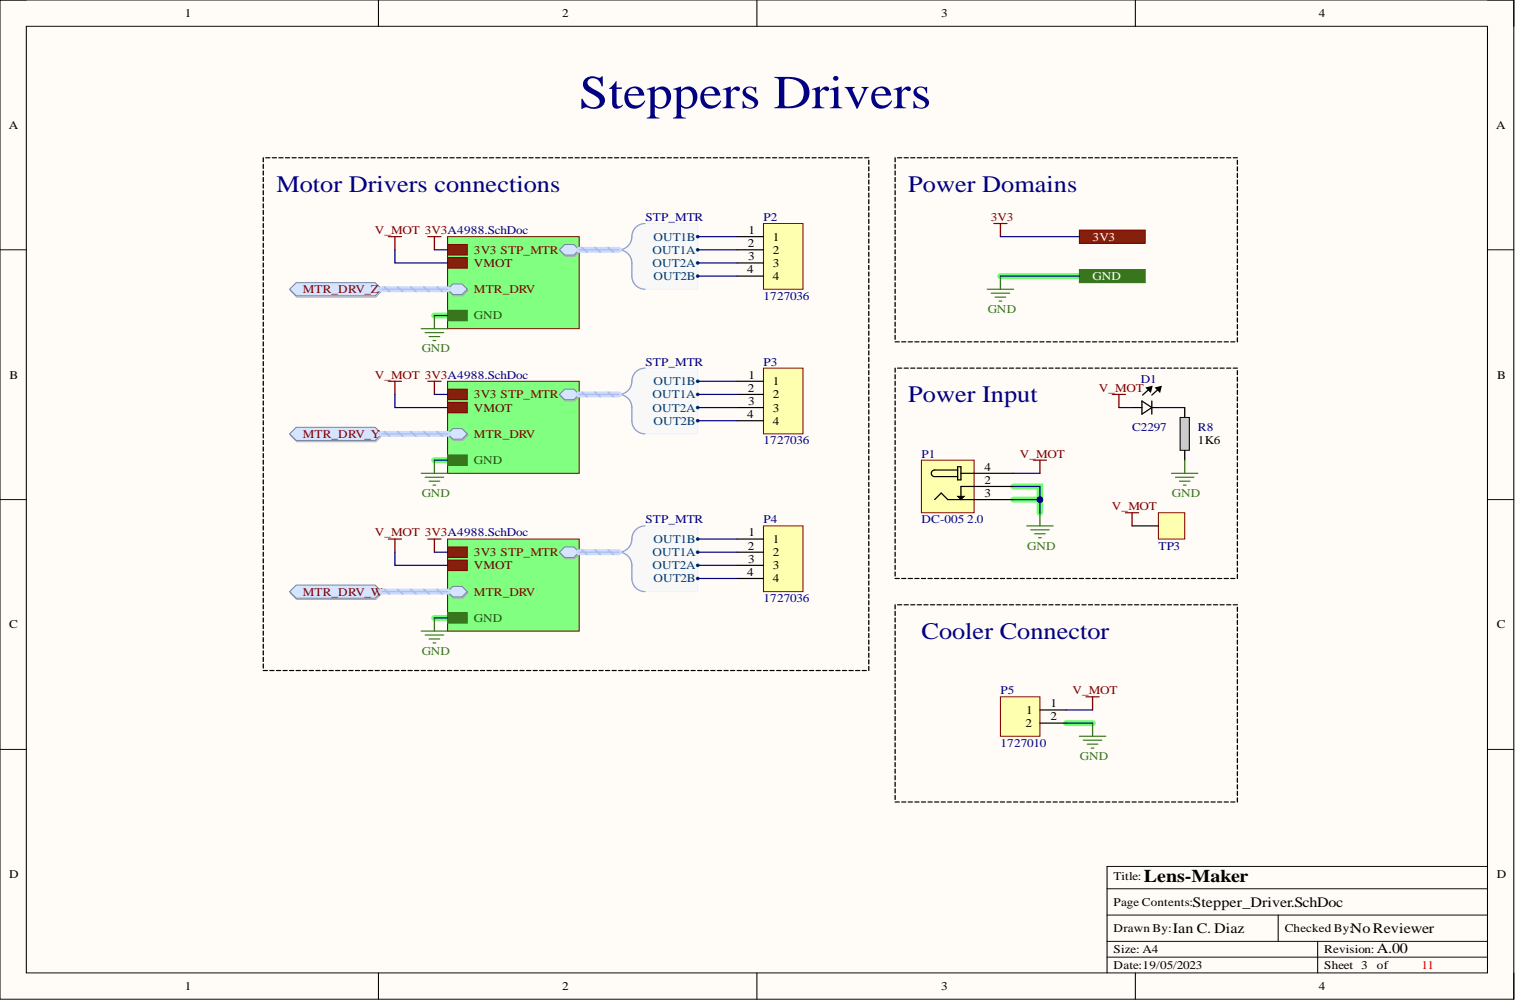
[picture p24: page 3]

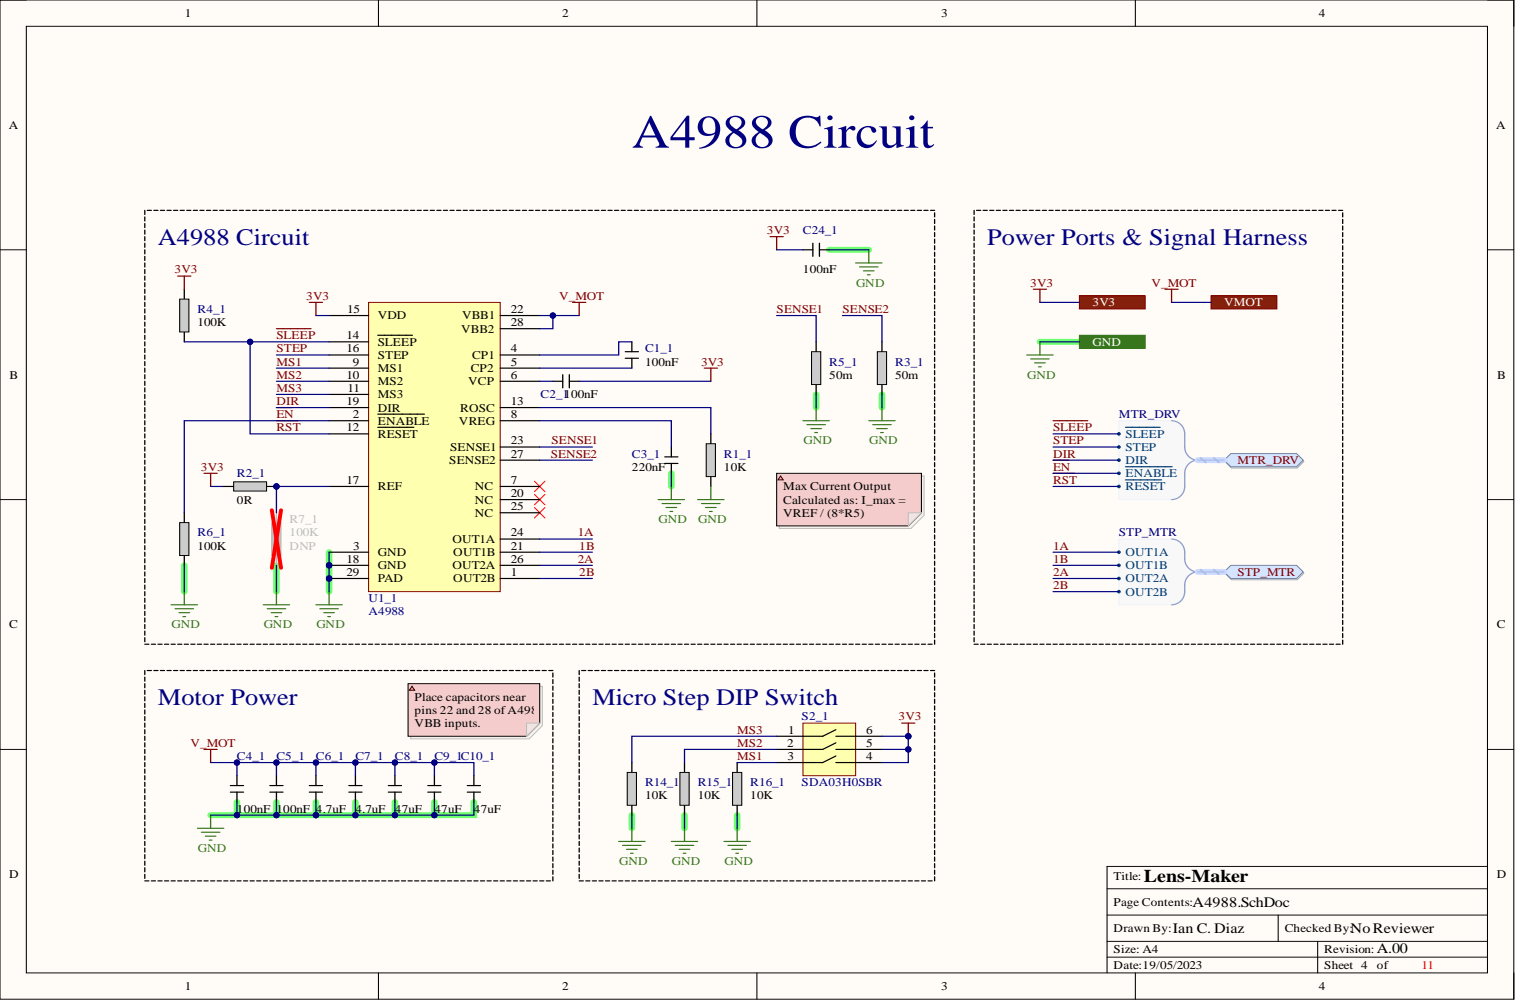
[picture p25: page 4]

Power Ports & Signal Harness

3V3 | RST | RESET 12

REF 17 | SENSE1

Micro Step DIP Switch

MS2 | 2
MS1 | 3

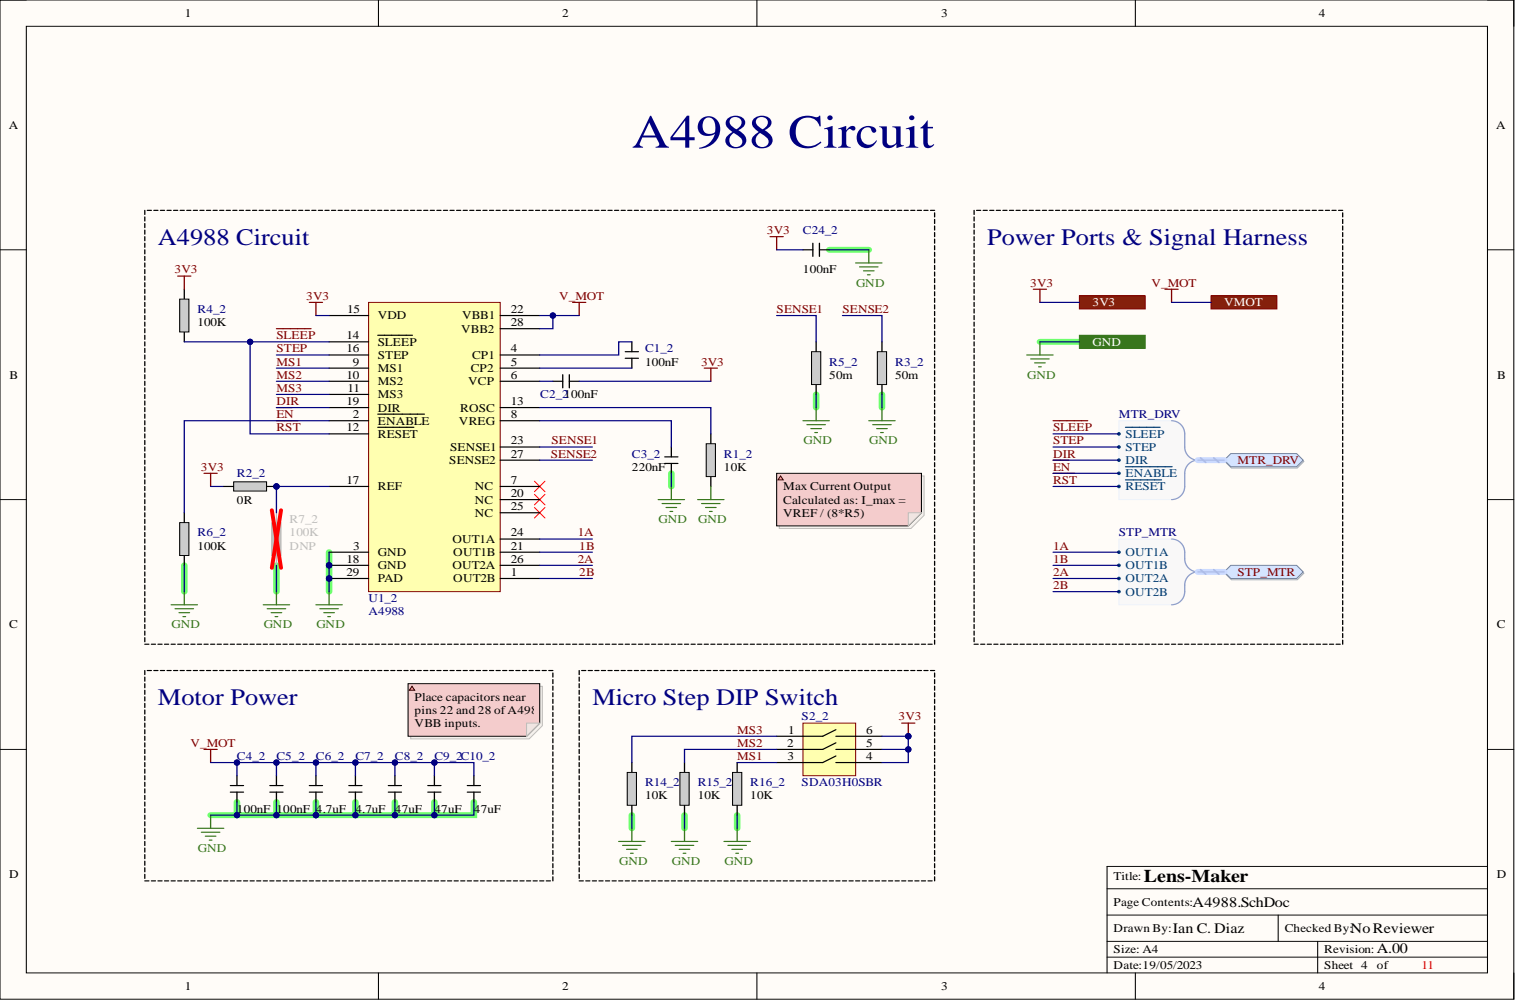
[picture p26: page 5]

Power Ports & Signal Harness

3V3 | RST | RESET 12

REF 17 | SENSE1

Micro Step DIP Switch

MS2 | 2
MS1 | 3

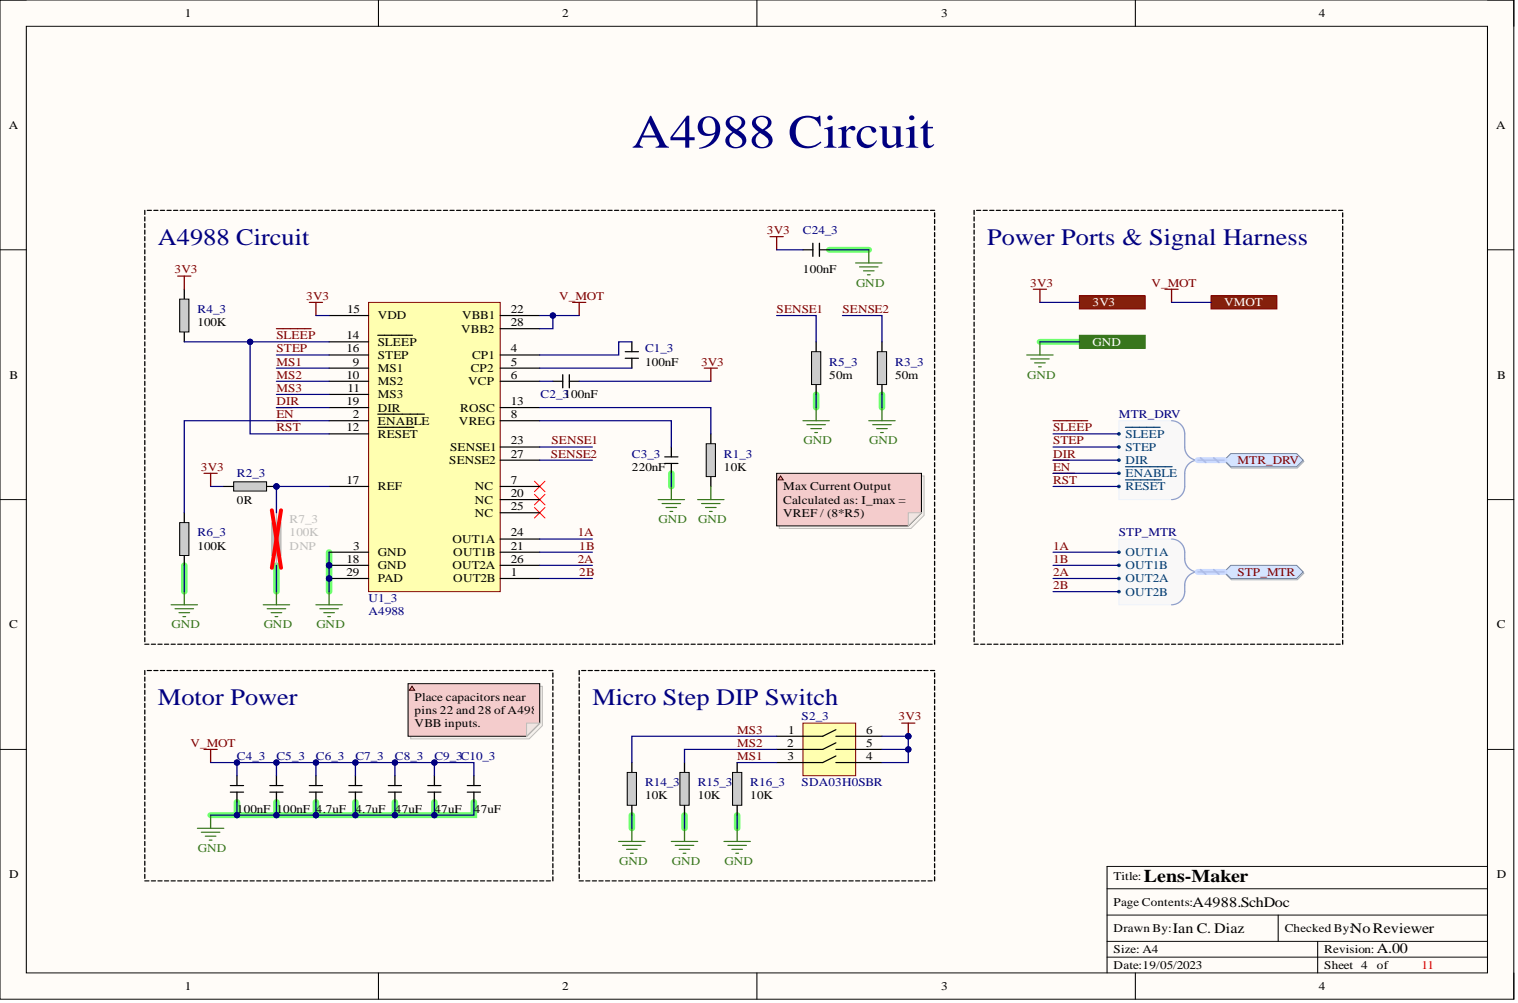
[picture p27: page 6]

Power Ports & Signal Harness

3V3 | RST | RESET 12

REF 17 | SENSE1

Micro Step DIP Switch

MS2 | 2
MS1 | 3

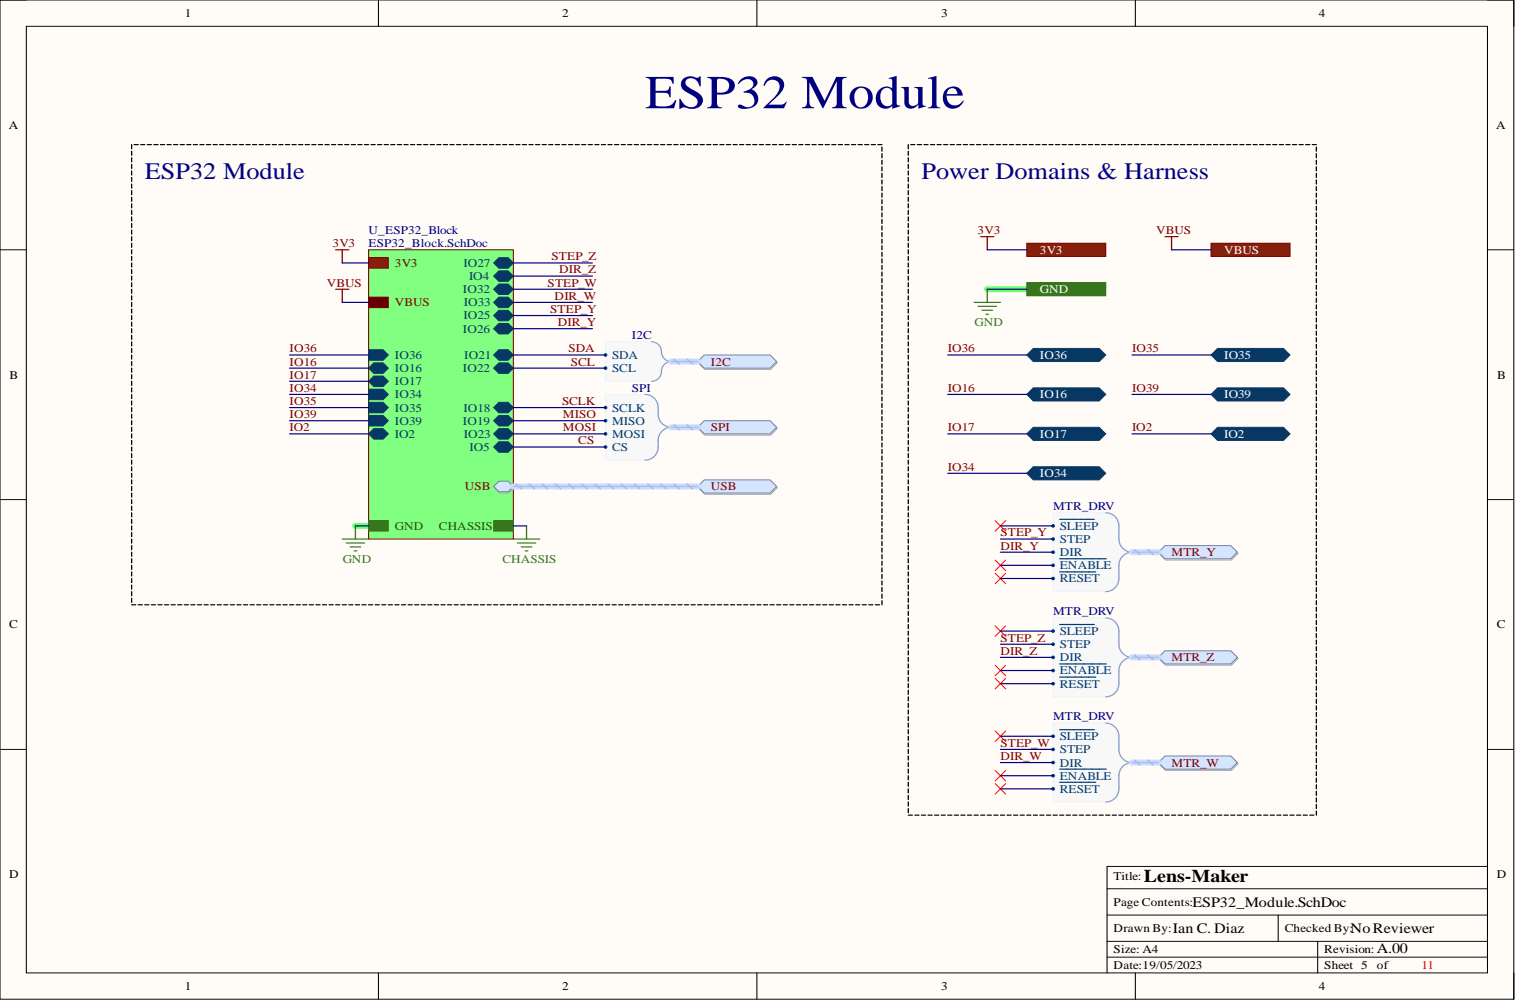
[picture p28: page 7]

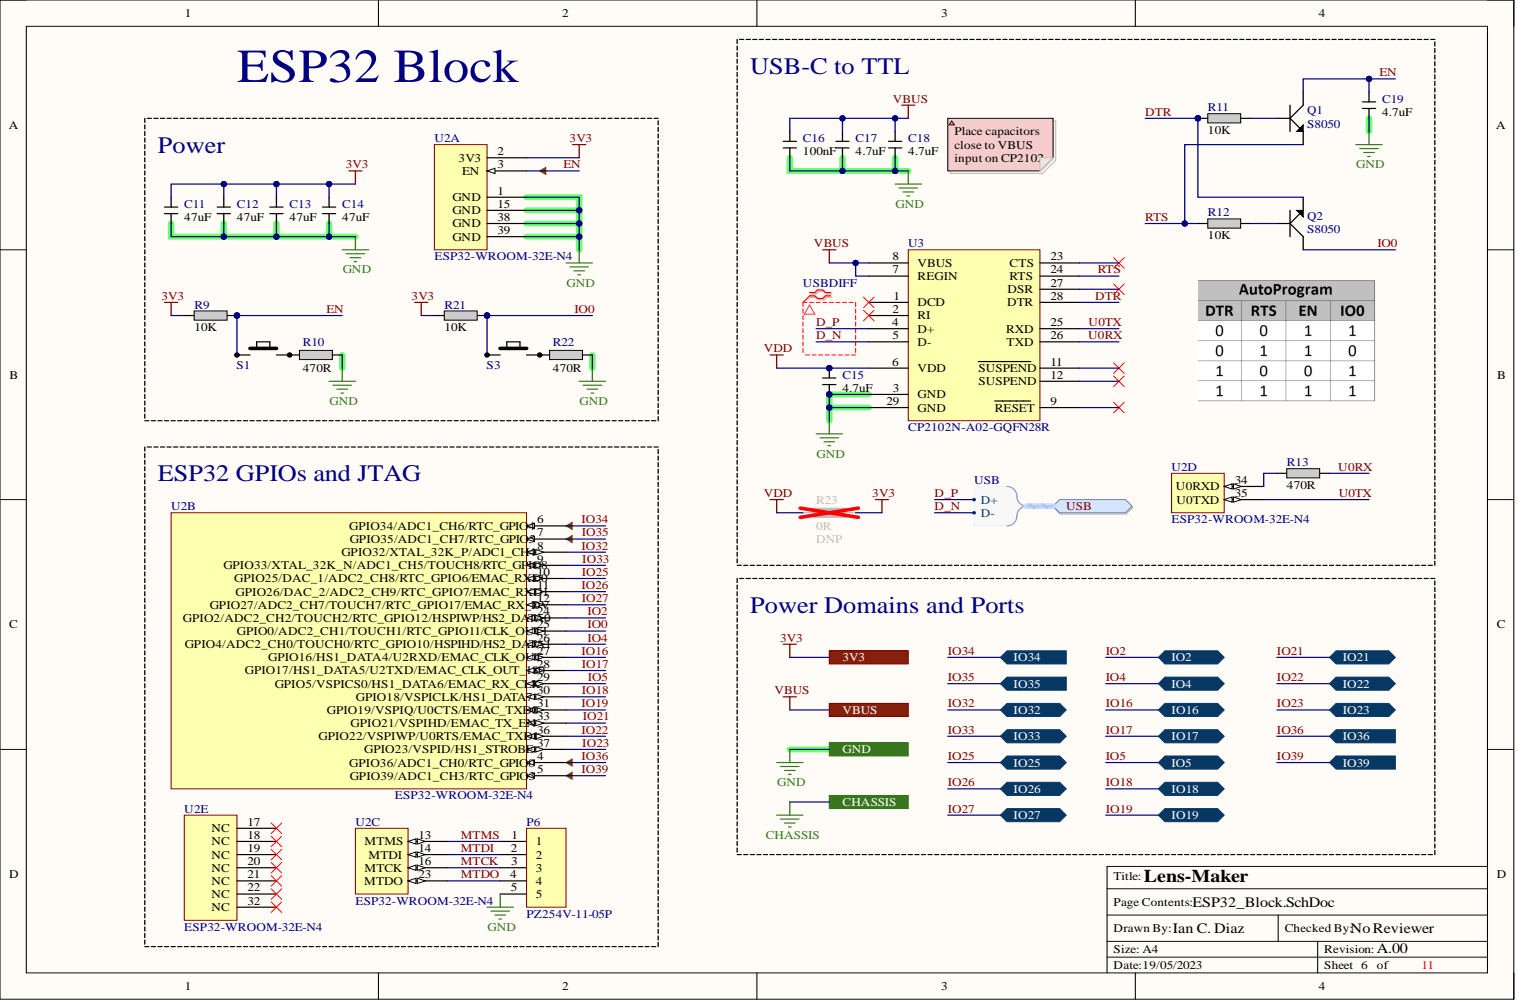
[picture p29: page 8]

Power Domains and Ports

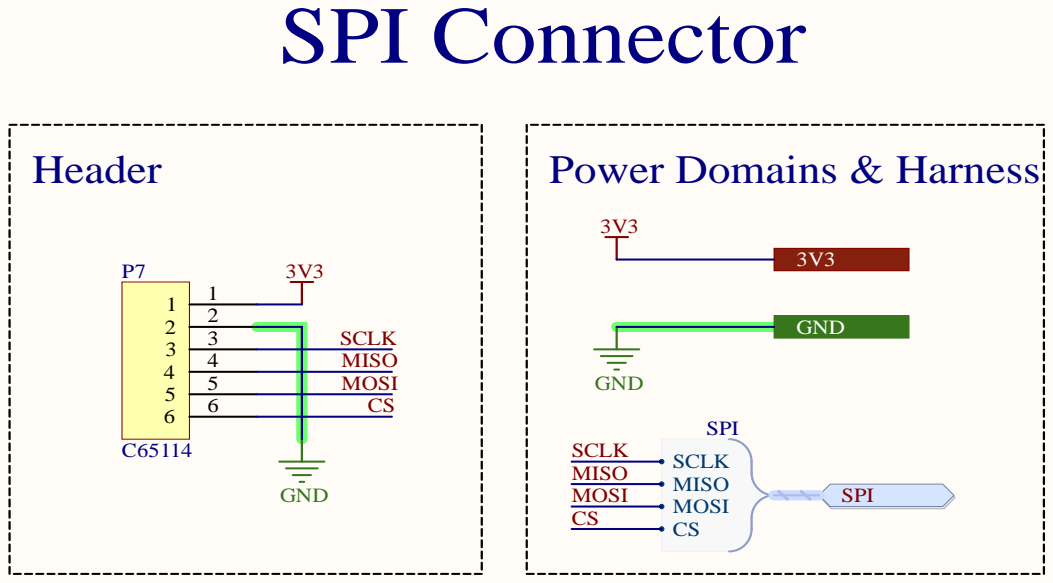
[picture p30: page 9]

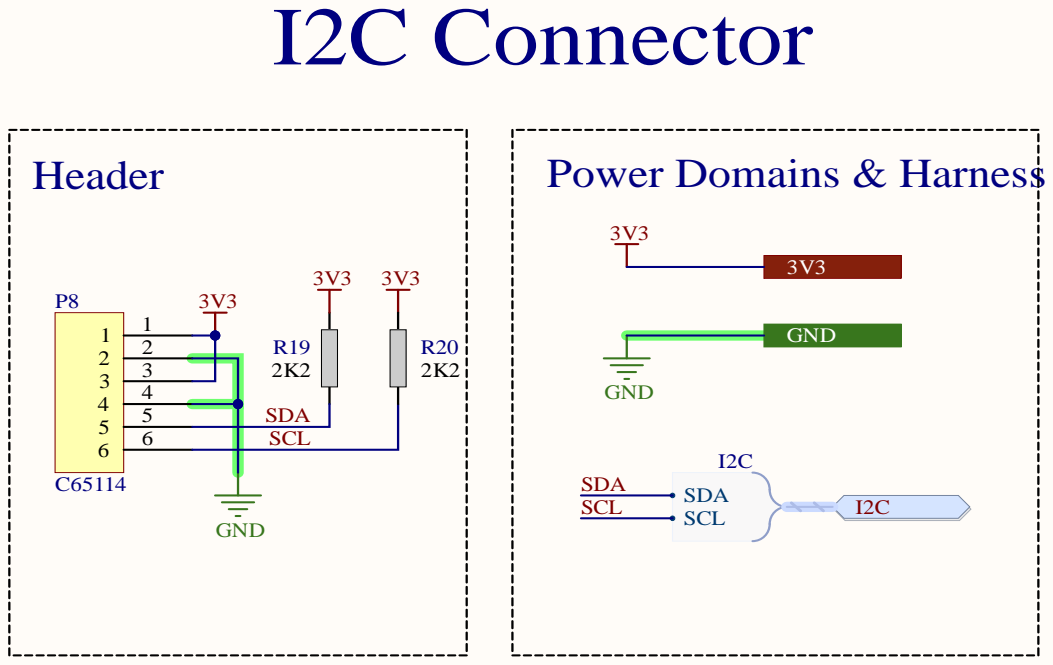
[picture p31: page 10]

5 | SD A

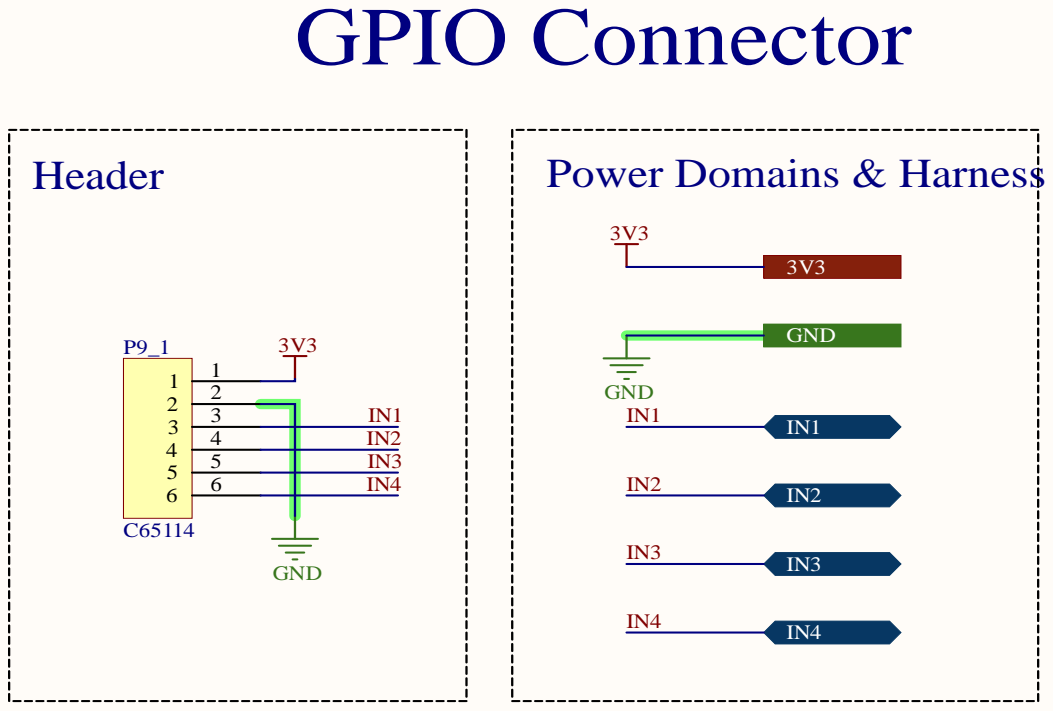
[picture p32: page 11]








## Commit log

2022-11-27 feat: Agrego hoja a4988
    [A4988.SchDoc, Lens-Maker.PrjPcb]
2022-11-27 fix: Agrego Steper_driver.schdoc
    [A4988.SchDoc, Lens-Maker.PrjPcb, Stepper_Driver.SchDoc]
2022-11-30 add: Agrego esquematico ESP32
    [A4988.SchDoc, ESP32_Block.SchDoc, Lens-Maker.PrjPcb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]
2022-11-30 add: Empiezo hoja de ESP32 Module
    [A4988.SchDoc, ESP32_Block.SchDoc, ESP32_Module.SchDoc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]
2022-12-06 fix: Sch and started PCB
    Se corrigieron cosas menores de los esquematicos, reubicando cosas, y
    se empezo con el PCB.
    [A4988.SchDoc, ESP32_Block.SchDoc, ESP32_Module.SchDoc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]
2022-12-07 fix: Routing and placement of components
    [Lens-Maker.PrjPcb, Stepper_Driver.SchDoc]
2022-12-08 fix> Fixed preliminary route
    [ESP32_Block.SchDoc, USB_Connector.SchDoc]
2022-12-13 add: Outjob
    [Bill of Materials-Lens-Maker.xlsx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]
2023-05-06 fix: Muchos cambios
    Se hicieron los siguientes cambios:
    - Se achico todo el tamaño del PCB, y se dejo una ventana para la antena
    - Se paso a un stackup de 6 capas
    - Se cambio el perfil de impedancia controlada de 100 Ohms a 90 Ohms
    - Se agrego la hoja de mechanical holes con 5 agujeros M3 y una conexion
    entre GND y CHASSIS
    - Se agrego la hoja del header SPI que estaba mal guardado en otro
    directorio.
    [A4988.SchDoc, ESP32_Block.SchDoc, ESP32_Module.SchDoc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]
2023-05-06 fix: Corrijo prolijidad esquemático
    Corrijo placement de designators y values en el esquemático, y modifico
    las resistencias del EN en el ESP32.
    [A4988.SchDoc, ESP32_Block.SchDoc, ESP32_Module.SchDoc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]
2023-05-06 feat: Empiezo ruteo
    [Stepper_Driver.SchDoc]
2023-05-07 feat: finish routing & top overlay
    Termine de rutear, por lo menos la primera pasada, y de acomodar los
    designators en el top overlay. Me queda ver si le agrego un conector
    para un cooler directo de los 12V para enfriar los drivers.
    [A4988.SchDoc]
2023-05-07 fix: Major mistake in Motors connectors
    Se corrijio un error grave que afectaba a los conectores de los motores,
    el tamaño del conector estaba mal diseñado y eso hacia que interfirieran
    entre si y no se puedan soldar.
    Ademas se agrego un conector para un cooler 12V.
    Queda pendiente agregar testpoints.
    [Stepper_Driver.SchDoc]
2023-05-07 feat: Agrego testpoints
    [ESP32_Module.SchDoc, Power.SchDoc, Stepper_Driver.SchDoc]
2023-05-07 fix: Cambio outjobs para que se ajusten a JLCPCB
    [A4988.SchDoc, Bill of Materials-Lens-Maker.xlsx, ESP32_Block.SchDoc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]
2023-05-07 fix: Errors in schematic, and some pcb errors
    [A4988.SchDoc, ESP32_Block.SchDoc, ESP32_Module.SchDoc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]
2023-05-08 fix: Agrego GND al conector de JTAG
    [A4988.SchDoc, Bill of Materials-Lens-Maker.xlsx, ESP32_Block.SchDoc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]
2023-05-08 feat: Agrego fab intructions y genero outputs
    [Bill of Materials.xlsx, Lens-Maker.PrjPcb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]
2023-05-08 chore: update outjob
    [Lens-Maker.PrjPcb]
2023-05-08 fix: SOT-223 footprint
    [Bill of Materials.xlsx, Lens-Maker.PrjPcb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]
2023-05-08 fix: Cambio pushbutton, agrego layer stack verification y corrijo fab instructions
    [Bill of Materials.xlsx, ESP32_Block.SchDoc, Lens-Maker.PrjPcb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]
2023-05-08 fix: Updated Terminal Blocks PNs and 3D models
    [Lens-Maker.PrjPcb, Stepper_Driver.SchDoc]
2023-05-09 fix: Cambio los dip switches y updateo el A4988
    [A4988.SchDoc, Lens-Maker.PrjPcb]
2023-05-09 fix: Cambio ruteo bobinas de pistas a planos
2023-05-09 Genero output files
    [Bill of Materials.xlsx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]
2023-05-11 Minor changer PCB Release
    [A4988.SchDoc, Bill of Materials.xlsx, ESP32_Block.SchDoc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]
2023-05-13 fix: BOM consolidation and BOOT button added
    [A4988.SchDoc, ESP32_Block.SchDoc, GPIO_Header.SchDoc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]
2023-05-14 fix: Holes Positions to mm
    [Lens-Maker_BOM.xlsx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]
2023-05-20 fix: Assembly drawing orientation and added assembly drawing bottom
    [Lens-Maker.PrjPcb, Lens-Maker_BOM.xlsx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]
2026-04-12 docs: Added rendered images to readme
    Generated rendered images with blender and added them to the readme
    file
    [Render.blend]
